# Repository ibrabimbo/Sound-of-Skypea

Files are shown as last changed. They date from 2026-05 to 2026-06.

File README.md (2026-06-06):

# The Sound of Skypea #

A battery-powered, aerial system that records the vibration of its body caused by free fall, then lands safely with a parachute.

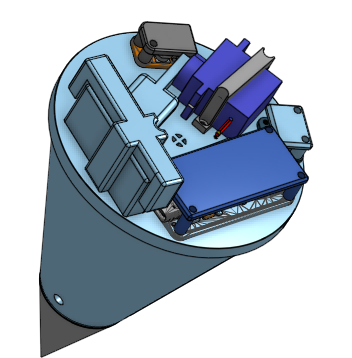
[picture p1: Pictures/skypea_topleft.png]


#Why?#

This year, I participated in the Hungarian CanSat competition, and last year in a local physics-engineering project. They had one thing in common: I sewed the parachute. In my time working on the model satellite for CanSat I learned a few things about designing aerial 3d prints and working with electronics. With my experience, I want to solve an age old question: is it possible to record the whistling sound a nerf bullet makes, from within its body, while still in the air? Physics call this effect the Helmholtz resonance. The rushing air on the outside vibrates the air within the flying chamber at a specific frequency, thus producing sound. 

I decided to build something that is capable of recording this, while also

* keeping complexity low  
* adding a landing system, so its reusable and safe  
* looking cool

# Assembly #

So you want one of these for yourself? No problem, the following guide will walk you through building it step by step.

#1\. Components#

You’ll have to source some components to build The sound of Skypea. You can find a list of everything needed in the table below. Links are included to make the shopping experience faster, but you can also go to alternative stores.

| Component | Price in USD | Description | Link |
| ----- | :---- | :---- | :---- |
| Adafruit Feather RP2040 Adalogger | 15 | main board | https://eu.mouser.com/ProductDetail/Adafruit/5980?qs=IKkN%2F947nfCnlS5PgbpnkA%3D%3D |
| Adafruit I2S MEMS ICS-43434  | 5 | microphone | https://eu.mouser.com/ProductDetail/Adafruit/6049?qs=olJun0bQHM88XeFsw90dVw%3D%3D |
| SG92R  | 6 | servo motor | https://eu.mouser.com/ProductDetail/Adafruit/169?qs=GURawfaeGuBHe0ZgcSsTjA%3D%3D |
| Adafruit MiniBoost 5V | 3 | booster | https://eu.mouser.com/ProductDetail/Adafruit/3661?qs=W0yvOO0ixfEzr%2F%252BSbf0hYQ%3D%3D |
| Li-Po Battery LP852040 | 8.67 | battery | https://www.akyga.com/products/873-li-po-battery-lp852040-akyga-aky0661-3-7v-620mah-pcm-jst-2-pin-connector-150mm.html |
| JST-PH 2.0 | 0.75 | battery cable | https://eu.mouser.com/ProductDetail/Adafruit/261?qs=GURawfaeGuDeA9XsXeF0ug%3D%3D |
| CNC KitchenHeat Set Inserts  | 15.47 | threaded insert | https://www.3djake.hu/cnc-kitchen/m25-standard-menetbetet?sai=15444 |
| cylinder head M 2 | 8 | screws | locally sourced / https://www.amazon.com/WZHUIDA-Screws-Assortment-M2x4mm-Washers/dp/B0F93XL3WK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 |
| Dupont wires | 6 | jumper wires | locally sourced / https://www.amazon.com/California-JOS-Breadboard-Optional-Multicolored/dp/B0BRTJXND9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 |
| MICROSD MEMORY CARD | 12.89 | sd card | https://eu.mouser.com/ProductDetail/DFRobot/FIT0394?qs=lqAf%2FiVYw9isxJnGlF1v2Q%3D%3D |
| SANWEAL120PCS/200PCS Fishing Weights Sinkers  | 7.95 | lead (fishing weights) | https://www.amazon.com/Fishing-Weights-SANWEAL-Removable-Including/dp/B096VLXPRJ/ref=sr\_1\_8?crid=2APA4P44H81OC\&dib=eyJ2IjoiMSJ9.nQvHi2aLW1y48RL51ZUzPd0F6E8PQ1SLJs0fs7tgkeYXlcJfFZuJQNBv2jagtvS9WUBzw8kRz4DnzINHXfDYB0q\_yqMwfaD2n5vmzZEvWExS8Klb9qG1RRlCi7egEFRrbrl7DZoieBwzMusvJMu9zx8-zD9i1ct4ojFCVH3eYmyNLAHY0Df8iL7TkMeQjdn5dtDUidgdY5HwmlMLCFK0O-ckBwSG\_W3GSh1FkLh2nU12f2lAdZo209C8g74Tk8BKnolkNCC0mls2jWQ5nv-6wL6m0LPhPI-GSUFWtLJrncA.xpFqImHCX1mhfefNpWzQDkMVmpndfLNeeYhprxQKBcE\&dib\_tag=se\&keywords=fishing%2Bweights\&qid=1779483113\&sprefix=fishing%2Bwei%2Caps%2C223\&sr=8-8\&th=1 |
| sancua Rectangle Tablecloth - 60 x 84 Inch | 9 | parachute material | https://www.amazon.com/sancua-Rectangle-Tablecloth-Resistant-Decorative/dp/B07XPTJKQC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 |
| Bright White Twine String | 7 | parachute string | https://www.amazon.com/White-Mason-Line-String-Construction/dp/B0BFCDFWVS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 |
| Space Trek Ripstop Nylon Parachute | 2 | complete parachute | make your own (recommended)/ https://www.amazon.com/Space-Trek-Ripstop-Parachutes-Rocketry/dp/B0D9ZJKVZY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 |
| Total | 106.73 | - | - |

The parts with amazon links are also easily sourced locally or from completely different sites, feel free to choose comfortable options.
The materials of the parachute (cloth and string) are completely for example, you can basically use any other types of these materials as long as it possesses basic endurance.
And even though you can buy a complete one, I recommend making one yourself.

Of course, electronics and screws are not “everything”. The body itself is 3d printed. You will need to print some parts to finish the build. A  3d printer is recommended, as well as some soldering skills.

# 2\. 3D printing #

Start by 3d printing the models, first the body (part 1\) and then the smaller components, if your printer isn’t capable of handling it all at once.

You can find the files here:

Step files: [Step](https://github.com/ibrabimbo/Sound-of-Skypea/tree/main/Step)

STL files:  [STL](https://github.com/ibrabimbo/Sound-of-Skypea/tree/main/STL)

Print each part once. Afterwards, you might have to use sandpaper to even out the threads on part 1 and 2, so that later they can be connected.

# 3\. Inserts #

You will find insertable screw threads in the BOM. This is where they come into play. Different parts hold together with screws, so you'll need to install these threaded inserts into the 3d parts.

1. Get yourself 10 inserts from the packet, they should be 2.5mmx4mm, as listed in the BOM.  
2. Locate the 10 holes on the top of the body (wider end).  
3. Populate the holes with the inserts one by one, based on the issued instructions received with the inserts.

# 4\. Soldering #

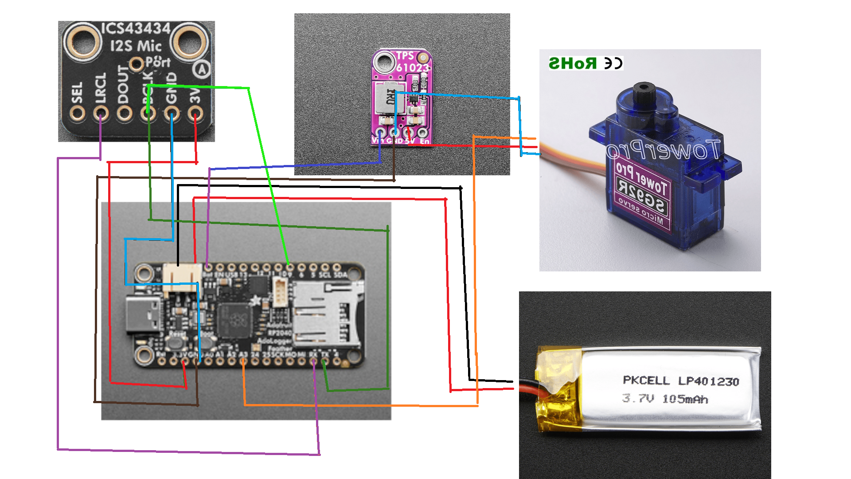
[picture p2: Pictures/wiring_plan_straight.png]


I understand that this diagram may not be my best work, here is a soldering list for clarification: [wiring](https://github.com/ibrabimbo/Sound-of-Skypea/tree/main/docs/wiring.md)

Follow this wiring diagram/list to connect then electronics. Keep in mind that the battery in the picture is a different one most likely, but that doesnt matter because jst connectors are the same. You might need to cut off a plug from the end of the servo’s wires, feel free to do so. Also, keep in mind that even at this stage, the microphone on the Adafruit I2S MEMS should be facing away , this is crucial because of the way it sits in the build and also allows you to differentiate the pins easier. The colors of the proposed wires dont mean anything, dont correlate them with purposes.

# 5.Software #
Download circuit python ( from [circuitpython.org](http://circuitpython.org) ) onto the adalogger and load the [.vscode](https://github.com/ibrabimbo/Sound-of-Skypea/tree/main/.vscode) on to it. But first, modify the servo_delay_seconds variable based on the last point of this README.

Then, enter the bootloader by holding down the “Boot” button, and while continuing to hold it, press and release  the “Reset” button. Keep holding the Boot button until the RPI-RPI2 drive. The RPI-RPI2 drive will disappear when the firmware is loaded.

# 6. Descend System #

To actually make it safe to use the system, we must build the parachute system. You can alternatively buy the amazon one from the BOM, but the following guide can help you make your own: [parachute](https://github.com/ibrabimbo/Sound-of-Skypea/blob/main/docs/parachute.md)

# 7\. Absolute Assembly # 
*Last but not least, you need to actually put the parts together.*  

Onshape (for assembly reference): open-> [assembly_link](https://github.com/ibrabimbo/Sound-of-Skypea/blob/main/docs/onshape.md)
( this assembly contains the 3d model of an adalogger with a hdmi connector instead of an sd card one, but it doesnt matter in our aspect )

1. Put your SD card into the adalogger.  
2. Place the adalogger onto the main body, like you see in the onshape file assembly.  
3. Screw it in, all 4 holes with the screws you bought earlier.   
4. Repeat this process with the booster as well as with the microphone.  
     
   *Pay attention to the wires and soldering, try not to damage your precious work.*  
     
5. Take the battery and place it on the main body based on the onshape assembly.   
6. Grab the battery attachment 3D part and place it on the battery, then screw it in.  
7. Repeat this process with the servo.   
8. Take your servo arm (3D printed part) and attach it to the servo’s axis (might have to remove the part it originally came with).  
     
   *Don’t position it down yet\! It should stay at a 90 degree angle for now.*  
     
9. Attach your parachute to the attachment point in the very center of the upper face of the main body (where all the other electronics and extra components go). Take the 8 strings coming out of the parachute and tie them around the attachment point’s middle part, by knotting one end of the string to the other, getting a fully secured parachute in the end.   
10. Fold the secured parachute in harmonica style (one left, one right, this helps it open), and place it on top of the main body, right above the attachment point, while paying attention to not one part of the parachute overlapping the walls.  
11. Close the arm of the servo onto the folded parachute, so that it holds it in place.  
12. Take the tip of the print (part 2\) and fill it up with the fishing weights\! This is crucial because it ensures that the system will fall in the correct position.  
13. Screw it into the narrower end of part 1\.

	*Thats it, you’re done.*

# 8\. How to "fly" it #

Choose a high point, like a building or a cliff, the important thing is that you know the height of which you are dropping the system from. It is preferable to be atleast 50 meters, since the longer the drop the better. 

For 50 meters, the servo_delay_seconds should be 1.20 seconds. Add 1 second every 30 meters, roughly calculating. Here is the formula to accurately calculate: t = √(2h/g). You get a figure, add five (later explained) and then subtract MINIMUM  2 and type it into the varieble. Preferrably substract more than 2 because this is the time that the parachute has to open under, in seconds. 

Climb up wherever you are dropping it from. If you followed the assembly carefully, your battery is not yet connected to the adalogger. Now is the time, connect it and from the moment of contact, start counting. After counting to 5 ( this is why we added it to the number), or alternatively starting a 5 second timer at the moment of connection ( recommended ), wait until it runs out and let go, so that the nose faces downwards. Pay attention not to fall with it tho, always grab onto something with your other arm.

ALWAYS HAVE SOMEBODY CLEAR THE SPACE UNDER YOU! It will fall slowly, but it is still not comfortable to be hit with. Trust me, I have done this many times, have someone look out under for bypassers.

I get it, this might sound a little dangerous. You are right, doing this in an urban area does require a lot of careful cooperation, but nonetheless is very cool if done right.. However, a drone-attachement is on the way, so that you can drop it from higher while also making the process easier. Stay tuned :)

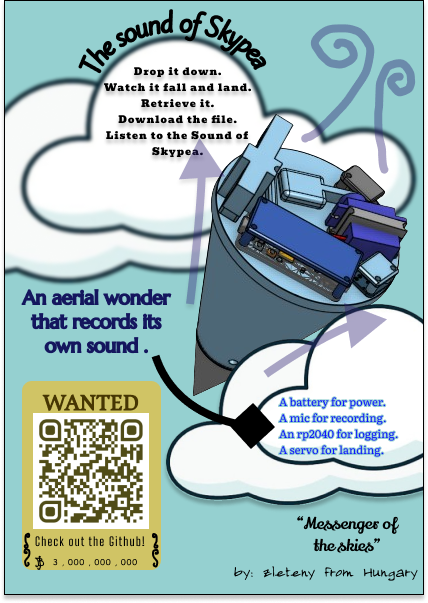
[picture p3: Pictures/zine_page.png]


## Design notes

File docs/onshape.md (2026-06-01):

[onshape](https://cad.onshape.com/documents/749d855f21592cb7ad435800/w/52d14e606b9725a530c02d20/e/6858fd8794da090b422fa8f4)

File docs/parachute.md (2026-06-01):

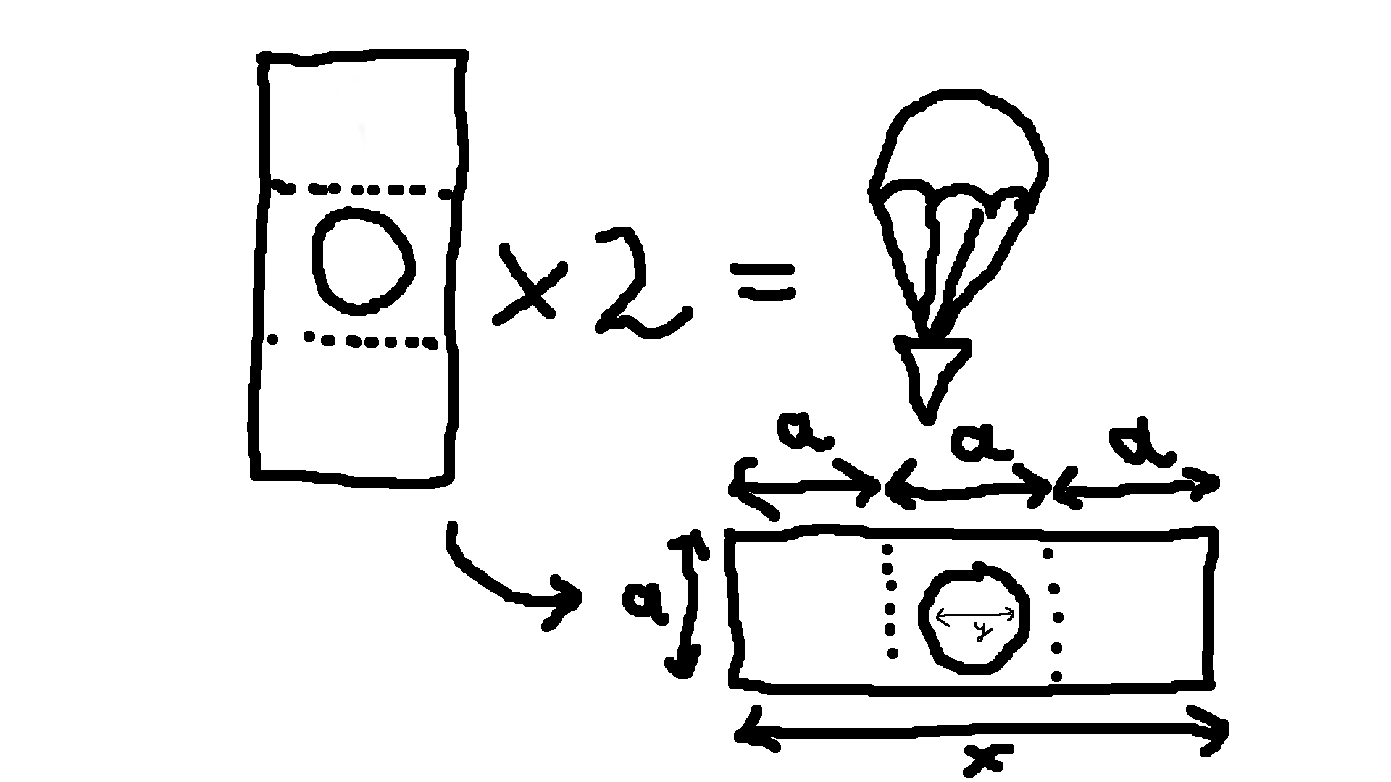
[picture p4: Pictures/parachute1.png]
 

The shown demonstration shows a panel of the parachute, which you will need two of, to make it a whole (seen in the equation).

**The measurements:**

*a:* 25 cm  
*x:* 75 cm  
*y (diameter of hole):*  20 cm

**1\.**

* Take your cloth and cut out two identical panels based on the instructions. I would recommend using a scissor but whatever feels comfortable and does the job is a great alternative.   
* *The dotted lines do not represent cutting lines, they are only there to visualize the 3:1 ratio of the sides of the rectangle.*

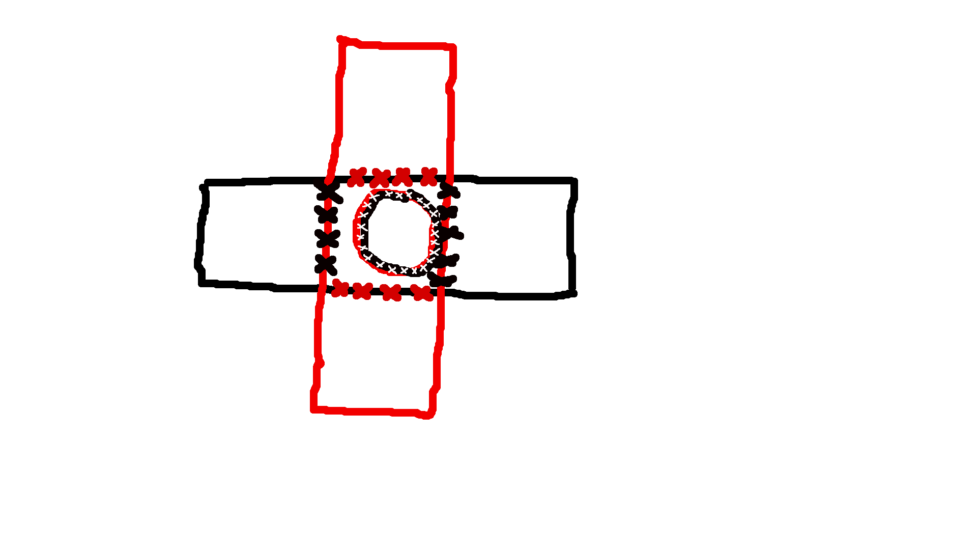
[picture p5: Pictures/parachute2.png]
  

**2\.**

* After you cut out the 2 panels, lay them on top of each other, with a 90 degree relative rotation, like you see in the picture. The two holes should perfectly overlap each other, so that you are able to see your working surface through the panels holes.   
* The ***x*** marks in the picture represent the lines that you should sew, follow these while the cloth is running through your machine, or when you are sewing by hand.   
* It is important that when sewing, you pay attention that each of your stitches actually goes through both panels, rather than just one.   
* Try to leave about 2mm of cloth between your sewing line and the very edge of the panel.  
*  If needed, you can prepare by fixating this position with needles and only sewing one side at a time. I would start with the sides of the “square” in the middle, and then sew together the outline of the circles. Use your most frequent linear setting on the machine, or sew accordingly by hand.

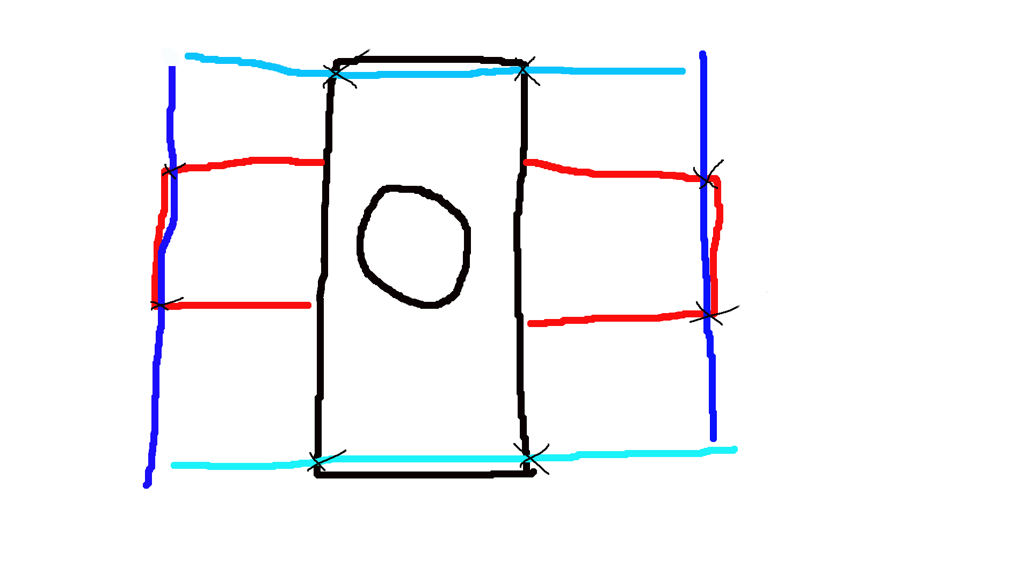
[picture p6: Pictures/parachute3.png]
  

**3\. Strings**  
 ***The blue lines represent the strings.***

* After you have sewn the two panels together, lay it out flat.   
* Take you string and cut 4 pieces, each 75 cm long. Then lay the pieces of string on top of your parachute like in the image, pay attention to leave about 2mm between the string and the very edge of the cloth.  
*  Position the strings so, that they are parallel to the sides of the parachute and overextend it by 25cm on each side. Then mark the points which are shown with ***x***  marks in the image on the strings. These are the points where the cloth should meet the string.   
* After this, start sewing the strings onto the parachute, one by one. Align the marks which you made earlier with the edge of the cloth, then start stitching. Use a zigzag pattern, and pull it real tight so that it holds the strings in place.

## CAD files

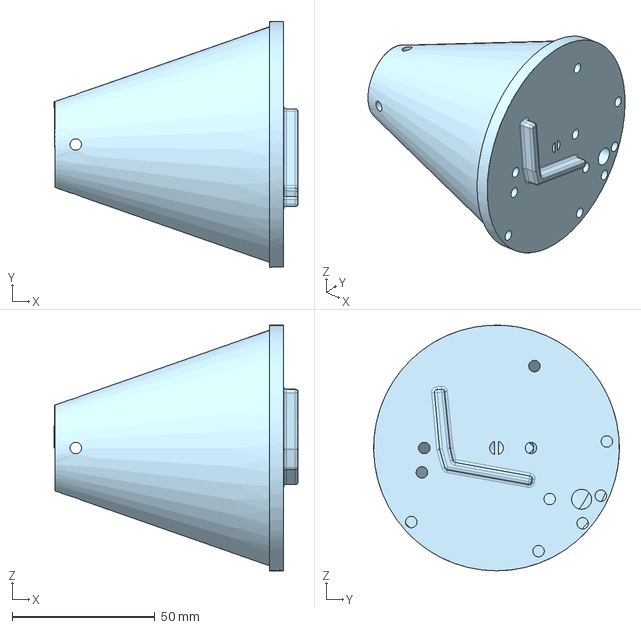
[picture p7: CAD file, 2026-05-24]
Step/main body v2.step
85.4 x 86.0 x 86.0 mm

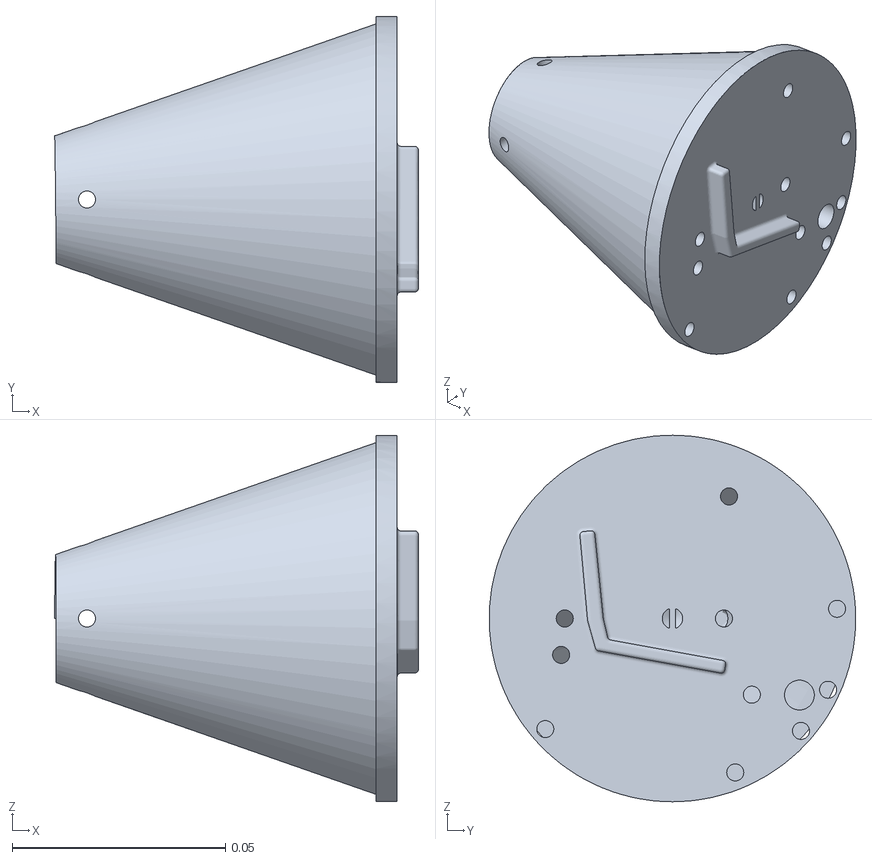
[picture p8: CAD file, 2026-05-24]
STL/main body stl.stl
0.0854 x 0.086 x 0.086

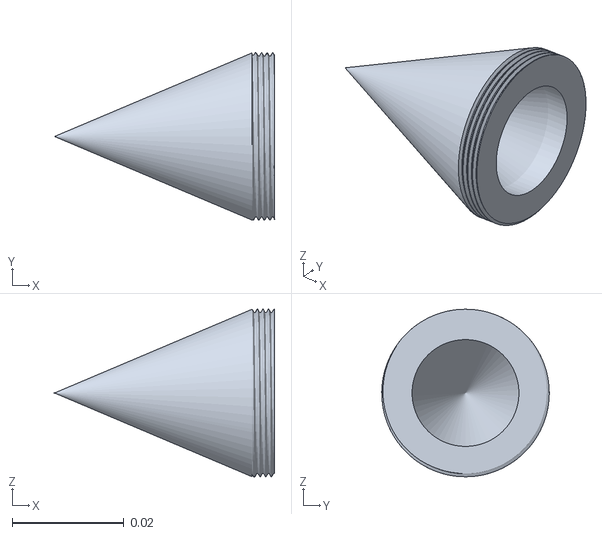
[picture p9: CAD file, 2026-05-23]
STL/main body - Part 2 (nose tip).stl
0.0394 x 0.03 x 0.03

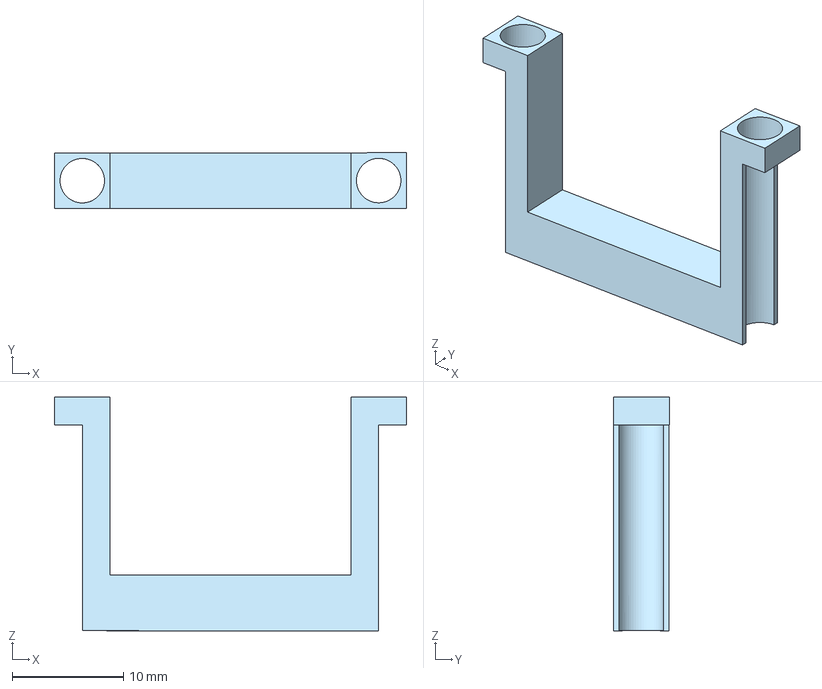
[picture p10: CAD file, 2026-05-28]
Step/servo_attach.step.step
31.7 x 5.03 x 21.0 mm

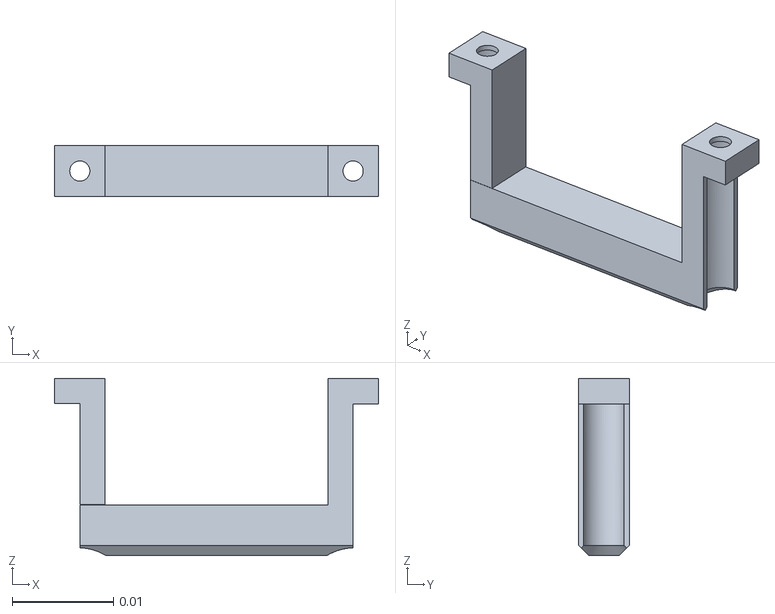
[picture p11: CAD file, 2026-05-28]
STL/servo_attach.stl
0.032 x 0.005 x 0.0175

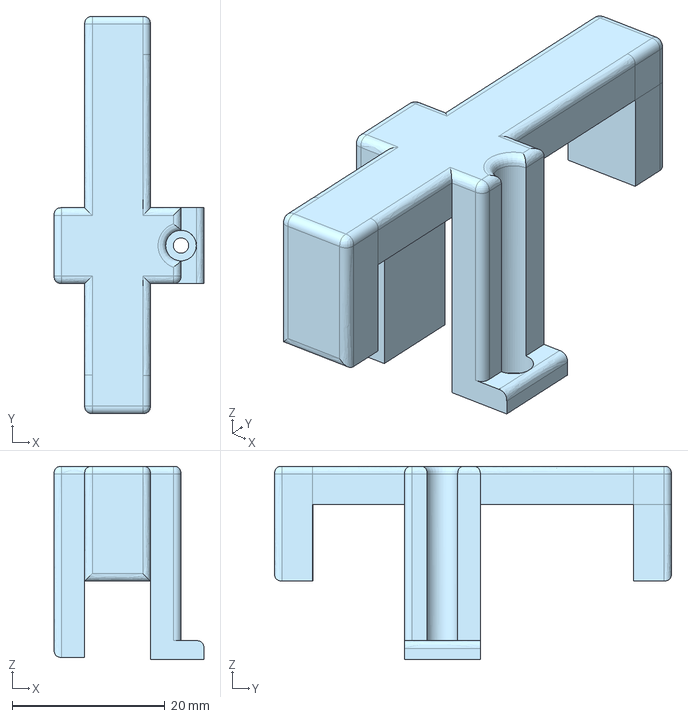
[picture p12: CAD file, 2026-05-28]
Step/battery_attach.step.step
19.6 x 51.9 x 25.3 mm

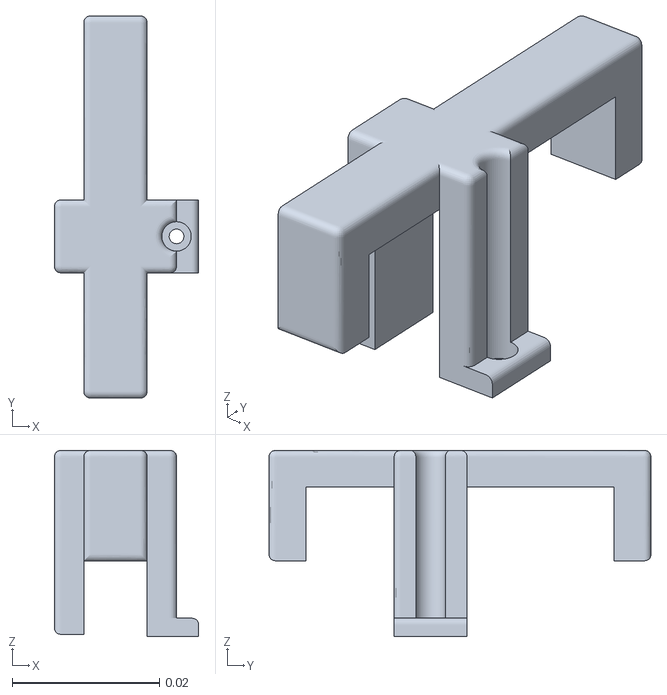
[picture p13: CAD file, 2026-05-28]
STL/battery_attach.stl
0.0196 x 0.0519 x 0.0253

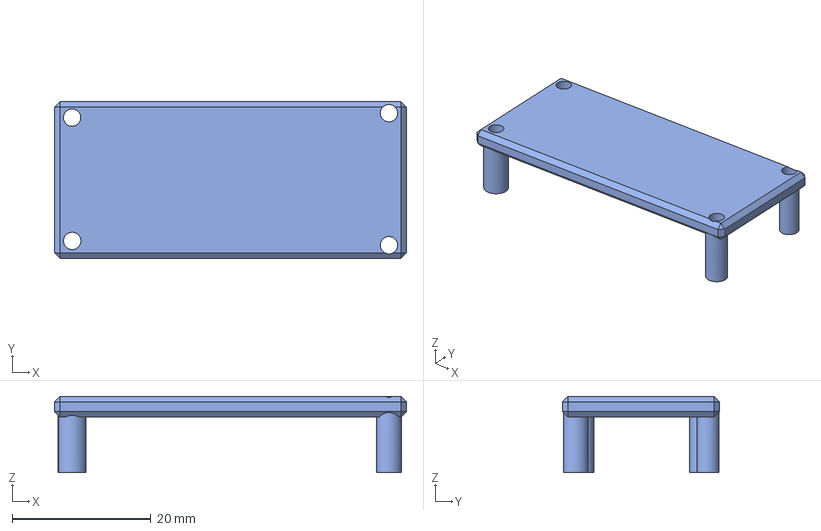
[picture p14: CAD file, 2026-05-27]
Step/adalogger cover.step.step
50.8 x 22.6 x 11.0 mm

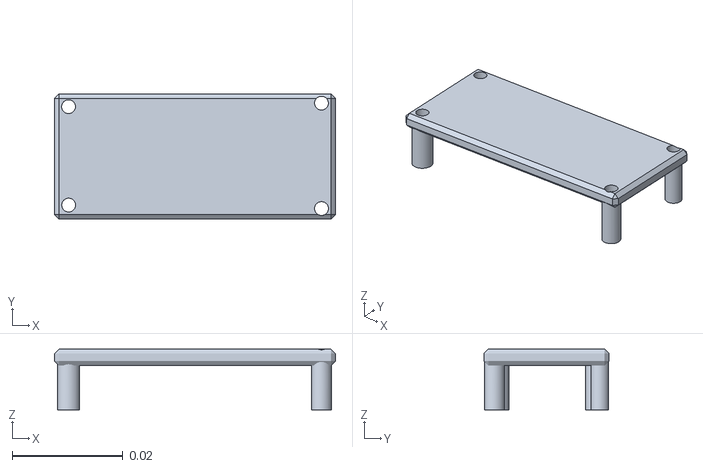
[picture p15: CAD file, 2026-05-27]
STL/adalogger_cover.stl.stl
0.0508 x 0.0226 x 0.011

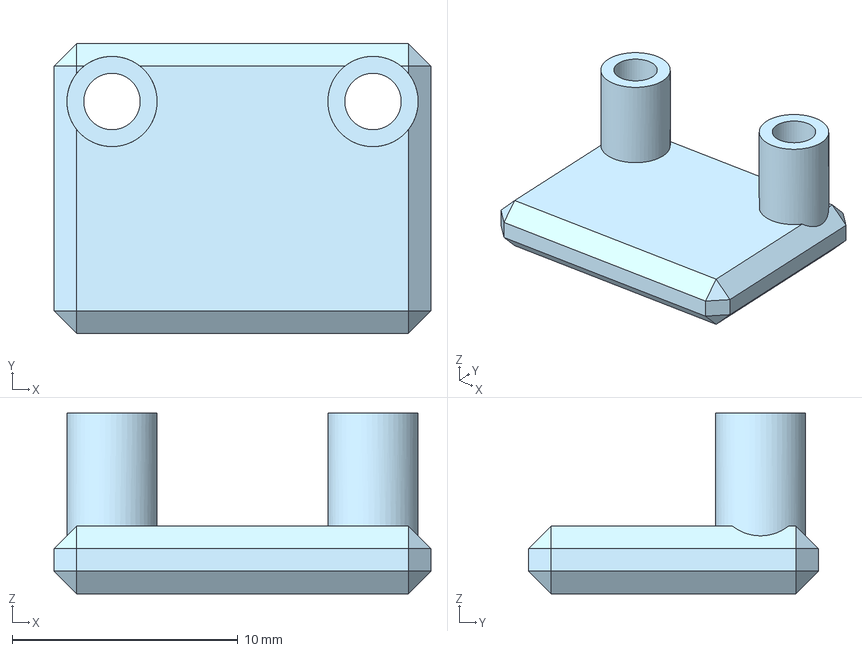
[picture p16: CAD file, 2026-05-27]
Step/mic_cover.step.step
16.7 x 12.8 x 8.00 mm

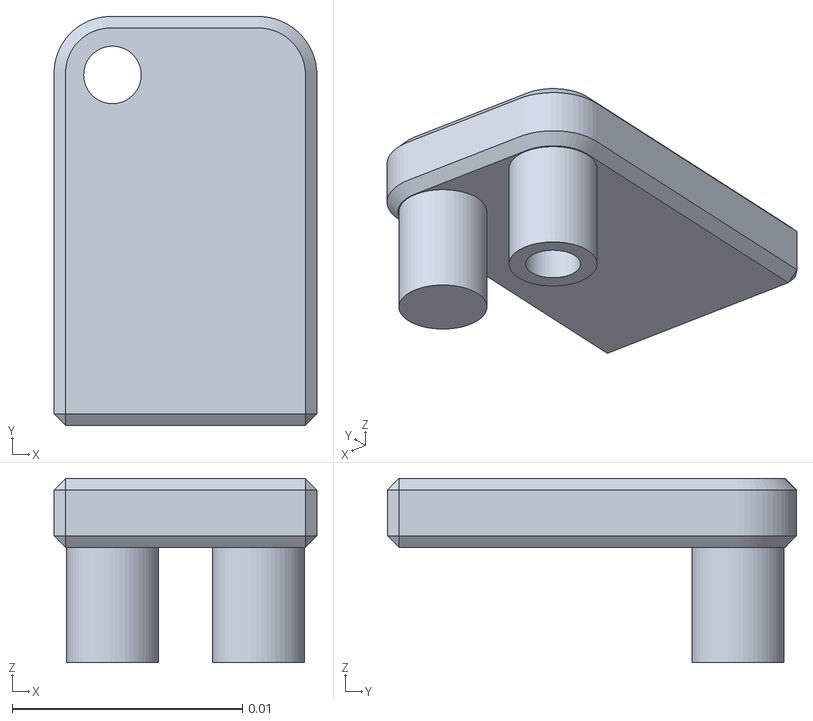
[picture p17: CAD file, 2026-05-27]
STL/booster_cover.stl.stl
0.0114 x 0.0178 x 0.008

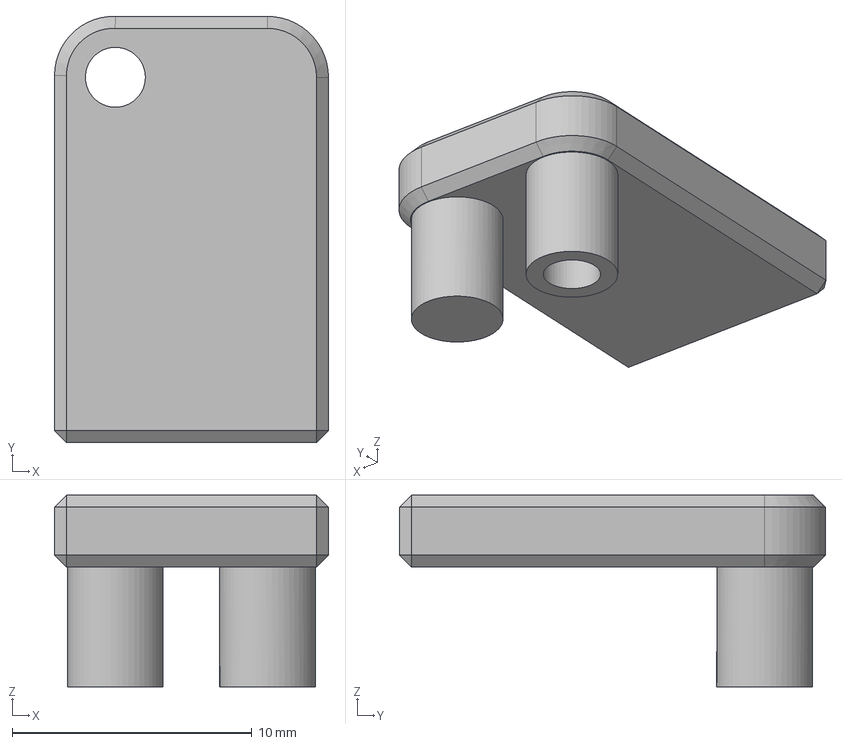
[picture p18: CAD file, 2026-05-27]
Step/booster_cover.step.step
11.4 x 17.8 x 8.00 mm

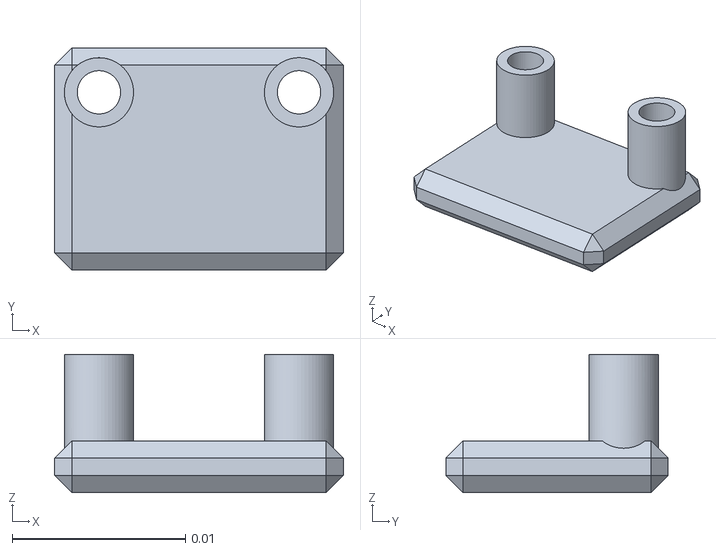
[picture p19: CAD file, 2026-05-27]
STL/mic_cover.stl.stl
0.0167 x 0.0128 x 0.008

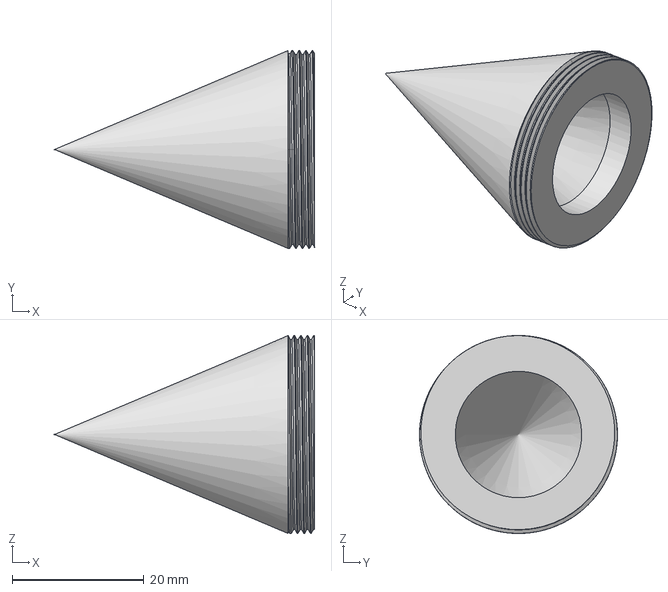
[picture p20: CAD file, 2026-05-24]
Step/Part Studio 1 - Part 2 (nosetip).step
39.4 x 30.0 x 30.0 mm

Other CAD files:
Step/servo arm.step
STL/servo arm.stl

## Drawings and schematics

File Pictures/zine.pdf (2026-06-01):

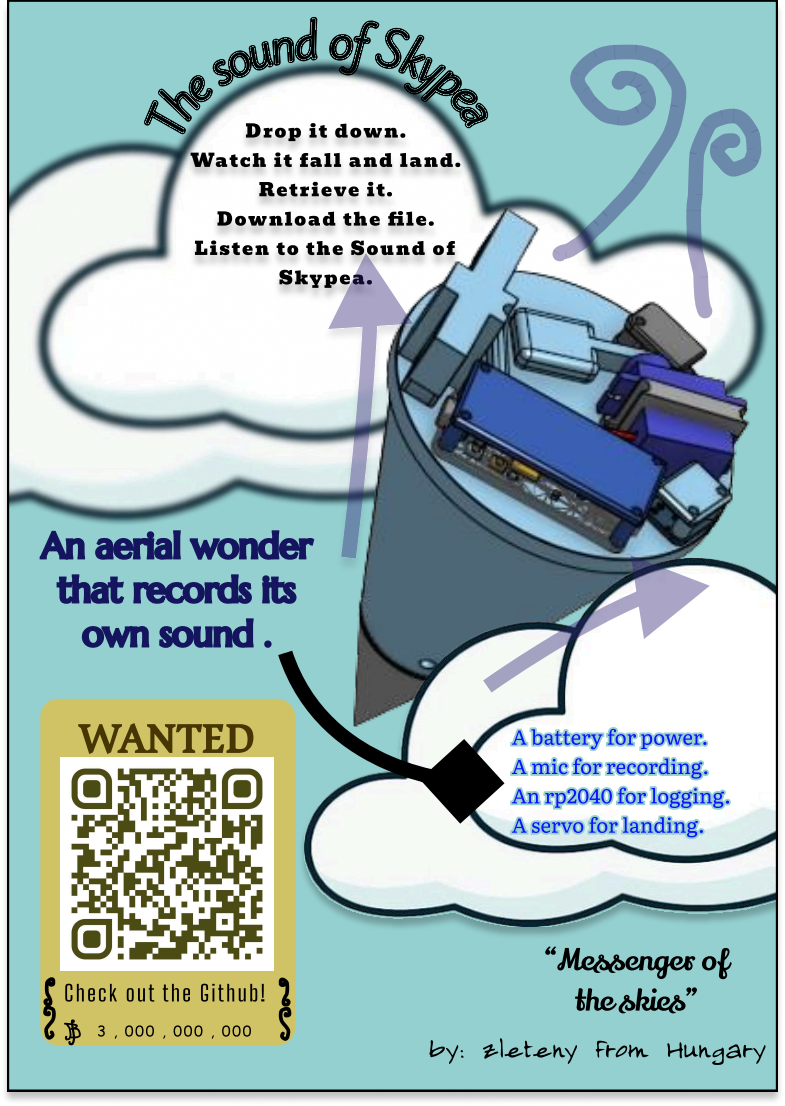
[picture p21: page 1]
Retrieve it .; Skypea .; own sound .; WANTED; by: zleteny from Hungary; “Messenger of; the skies”

Drop it down .

Watch it fall and land .

Download the file .

Listen to the Sound of

An aerial wonder

that records its

A battery for power.

A mic for recording.

An rp2040 for logging.

A servo for landing.

Ch e c k out th e G ithub!

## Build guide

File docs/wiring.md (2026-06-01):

adalogger 9 - mic dout

adalogger jst - battery jst

adalogger bat - booster vin

adalogger 3.3v - mic 3v

adalogger gnd - mic gnd

adalogger gnd - booster gnd

adalogger a3 - servo (yellow)

adalogger rx - mic lrcl

adalogger tx - mic bclk 

booster gnd - servo (brown)

booster 5v - servo (red)
